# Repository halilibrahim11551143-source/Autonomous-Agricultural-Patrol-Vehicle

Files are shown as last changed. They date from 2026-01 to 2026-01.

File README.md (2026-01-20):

# Görüntü İşleme Destekli Otonom Tarım Devriye Aracı
## Autonomous Agricultural Patrol Vehicle with Deep Learning

[cite_start]Bu proje, Manisa Celal Bayar Üniversitesi bünyesinde "Lisans Bitirme Tasarımı" olarak geliştirilmiştir[cite: 48, 63]. [cite_start]Tarım arazilerinde otonom navigasyon yaparak bitki hastalıklarını gerçek zamanlı tespit eden ve noktasal (hedefli) ilaçlama gerçekleştiren entegre bir mekatronik sistemdir [cite: 126-127, 255].

### 🛠 Mühendislik Yaklaşımı ve Bileşenler
[cite_start]Sistem; algılama, karar verme ve eylem olmak üzere üç temel katmandan oluşmaktadır[cite: 128, 176]:

* [cite_start]**Yüksek Seviye Kontrol (Vision):** Raspberry Pi 5 üzerinde koşan YOLOv8n-cls modeli[cite: 303, 335].
* [cite_start]**Düşük Seviye Kontrol (Actuation):** Arduino Nano ile diferansiyel sürüş ve pompa yönetimi[cite: 303, 338, 399].
* [cite_start]**Donanım Kararı:** NVIDIA Jetson Nano yerine Raspberry Pi 5 seçilerek, sahada daha yüksek güç verimliliği ve fiyat/performans dengesi hedeflenmiştir [cite: 395-397].

### 📊 Performans Analizi (Sayısal Bulgular)
[cite_start]Elde edilen sonuçlar sistemin gerçek zamanlı tarımsal operasyonlara uygunluğunu kanıtlamaktadır[cite: 409, 446]:

| Parametre | Teknik Değer | Kaynak (Tez) |
| :--- | :--- | :--- |
| **Model Doğruluk Oranı (Top-1)** | [cite_start]%97.2 | [cite: 413, 418] |
| **Görüntü İşleme Hızı (Inference)** | [cite_start]30 ms / kare | [cite: 424, 448] |
| **Sistem Tepki Süresi** | [cite_start]45 ms | [cite: 450, 448] |
| **Eğitim Veri Seti** | [cite_start]16.011 Görüntü (10 Sınıf) | [cite: 373, 379] |
| **Otonom Hareket Hızı** | [cite_start]0.5 m/s | [cite: 451, 448] |

### 📂 Depo Hiyerarşisi
* [cite_start]**/Software/High_Level:** Ana otonom kontrol ve AI çıkarım kodları [cite: 514-515].
* **/Software/Embedded:** Eyleyici motor ve servo kontrol algoritmaları [cite: 585-588, 681].
* [cite_start]**/Software/Tools:** Veri ön işleme (`data_split.py`) ve sistem tanılama (`diagnostics.py`) araçları[cite: 848, 910].
* **/Hardware/CAD:** SolidWorks üzerinde tasarlanan parametrik şasi modelleri[cite: 315, 326].
* [cite_start]**/Documentation:** Akademik bitirme tezi tam metni (PDF) [cite: 47-51].

### 🔍 Neden Özgün?
[cite_start]Sistem, sadece bir yazılım projesi değil; mekanik tasarımı, devre mimarisi ve gömülü yazılımı ile bütünleşik bir mekatronik tasarımıdır[cite: 128, 250, 456]. [cite_start]Hatalı ilaçlama oranının %2.1'de tutulması, sürdürülebilir akıllı tarım uygulamalarına doğrudan katkı sağlamaktadır[cite: 448, 465].

---
**Geliştirici:** Halil İbrahim KURNAZ

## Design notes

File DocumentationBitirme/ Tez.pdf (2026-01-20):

T.C.
MANİSA CELAL BAYAR ÜNİVERSİTESİ HASAN FERDİ TURGUTLU TEKNOLOJİ FAKÜLTESİ

MEKATRONİK MÜHENDİSLİĞİ BÖLÜMÜ

GÖRÜNTÜ İŞLEME DESTEKLİ
OTONOM TARIM DEVRİYE ARACININ TASARIMI VE UYGULAMASI

Ulaş Can ÇAKMAK
222808014

Halil İbrahim KURNAZ
222808057

Yavuz SARI
222812001

Danışman
Arş. Gör. Dr. Göksu TAŞ

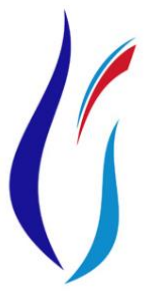
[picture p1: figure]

MANİSA–2025

PROJE ONAYI

Ulaş Can ÇAKMAK , Halil İbrahim KURNAZ , Yavuz SARI tarafından hazırlanan “Görüntü İşleme Destekli Otonom Tarım Devriye Aracının Tasarımı ve Uygulaması”başlıklı bu çalışma, Manisa Celal Bayar Üniversitesi Hasan Ferdi Turgutlu Teknoloji Fakültesi Mekatronik Mühendisliği Bölümü’nde Lisans Bitirme Tasarım Projesi olarak hazırlanmış ve aşağıda imzaları bulunan jüri tarafından 2025 yılında kabul edilmiştir.

Danışman | Arş. Gör. Dr. Göksu TAŞ

Manisa Celal Bayar Üniversitesi

TAAHHÜTNAME

Bu tez çalışmasının Manisa Celal Bayar Üniversitesi Hasan Ferdi Turgutlu Teknoloji Fakültesi Mekatronik Mühendisliği Bölümü Lisans Bitirme / Tasarım Projesi kapsamında, akademik etik kurallara uygun olarak tarafımdan hazırlandığını; çalışmada kullanılan tüm kaynakların bilimsel kurallara uygun şekilde atıf yapılarak belirtildiğini beyan ederim.

Ulaş Can Çakmak
Halil İbrahim KURNAZ
Yavuz SARI

I

İÇİNDEKİLER
Sayfa
İÇİNDEKİLER | I
SİMGELER VE KISALTMALAR DİZİNİ | II
ŞEKİLLER DİZİNİ | III
TABLOLAR DİZİNİ | IV
TEŞEKKÜR | V
ÖZET | VI
ABSTRACT | VI I

II

EKLER | 33
EK A. Raspberry Pi Ana Yazılımı | 33
EK B. Ardunio Gömülü Kontrol Yazılımı | 34
EK C. Model Eğitim Yazılımı | 37
EK D. Ardunio Hareket ve İlaçlama Kontrol Yazılımı | 38
EK E. Phyton Kamera Donanım Test Yazılımı | 41
EK F. UART Seri Haberleşme Test Kodu | 43
EK G. Phyon Sistem Bağımlılık ve Sistem Kontrol Yazılımı | 43
EK H. Phyton Model Doğrulama Çıkarım ve Test Yazılımı | 44
EK I. Phyton Veri Ön İşleme ve Veri Seti Bölümleme Yazılımı | 45
EK J. Phyton Temel Model Mimarisi ve Analiz Yazılımı | 47
EK K. Phyton Sistem Hata Ayıklama ve Tanılama Yazılımı | 48
EK L. Phyton Gerçek Zamanlı Görüntü Kalibrasyon Yazılımı | 50
EK M. Phyton Statik Görsel Üzerinde Tahmin Yazılımı | 51
EK N. Phyton Sistem Başlatıcı ve Süreç Yöntecisi Yazılımı | 52
EK O. Phyton OpenCV Sürüm ve Grafik Doğrulama Yazılımı | 53
ÖZGEÇMİŞ | 56

III

SİMGELER VE KISALTMALAR DİZİNİ

YZ | Yapay Zekâ
ESA | Evrişimli Sinir Ağı
CNN | Convolutional Neural Network (Evrişimli Sinir Ağı)
CPU | Merkezi İşlem Birimi
GPU | Grafik İşlem Birimi
KKS | Küresel Konumlama Sistemi
Nİ | Nesnelerin İnterneti
DGM | Darbe Genişlik Modülasyonu
RGB | Kırmızı, Yeşil, Mavi Renk Uzayı
ROS | Robot İşletim Sistemi
RTOS | Gerçek Zamanlı İşletim Sistemi
UART | Evrensel Asenkron Alıcı-Verici
USB | Evrensel Seri Veri Yolu
YOLO | You Only Look Once (Gerçek Zamanlı Nesne Algılama Algoritması)

IV

ŞEKİLLER DİZİNİ

Sayfa

Şekil 3.1. Arduino tabanlı ilaçlama sisteminin detaylı yazılım akış diyagramı .........7

Şekil 3.2. Otonom araca ait mekanik parçaların üç boyutlu CAD görünümleri........11

Şekil 4.2. Gerçek zamanlı domates yaprağı erken yanıklık hastalığı tespit çıktısı....25

V

TABLOLAR DİZİNİ
Sayfa

VI

TEŞEKKÜR

Çalışmamın her aşamasında bilgi ve deneyimleriyle bana yol gösteren, proje sürecinde karşılaştığım teknik ve akademik problemlerin çözümünde desteğini esirgemeyen danışman hocam Arş. Gör. Dr. Göksu TAŞ’a en içten teşekkürlerimi sunarım.

Lisans öğrenimim boyunca mesleki ve akademik gelişimime katkı sağlayan, bilgi birikimleri ve tecrübeleriyle ufkumu genişleten Manisa Celal Bayar Üniversitesi Hasan Ferdi Turgutlu Teknoloji Fakültesi Mekatronik Mühendisliği Bölümü öğretim elemanlarına teşekkür ederim.

Proje süreci boyunca manevi desteklerini her zaman hissettiğim, fikir ve önerileriyle katkı sağlayan arkadaşlarıma; öğrenim hayatım boyunca maddi ve manevi desteğini hiçbir zaman esirgemeyen aileme sonsuz teşekkürlerimi sunarım.

Ulaş Can ÇAKMAK
Halil İbrahim KURNAZ
Yavuz SARI

Manisa, 2025

VII

ÖZET

Mekatronik Mühendisliği Tasarımı Raporu

Görüntü İşleme Destekli Otonom Tarım Devriye Aracının Tasarımı ve Uygulaması

Ulaş Can ÇAKMAK
Halil İbrahim KURNAZ
Yavuz SARI

Manisa Celal Bayar Üniversitesi Hasan Ferdi Turgutlu Teknoloji Fakültesi Mekatronik Mühendisliği Bölümü

Danışman: Arş. Gör. Dr. Göksu TAŞ

Bu çalışmada, tarım alanlarında bitki sağlığının izlenmesi, hastalıkların erken tespiti ve tarımsal ilaç kullanımının optimize edilmesi amacıyla görüntü işleme destekli otonom bir tarım devriye aracı tasarlanmış ve uygulanmıştır. Geliştirilen sistem, tarım arazisi üzerinde otonom olarak hareket edebilmekte, bitkilerden elde edilen görüntüleri yapay zekâ tabanlı yöntemlerle analiz ederek hastalık belirtilerini
tespit | edebilmekte | ve | yalnızca | hastalıklı | bölgelerde | noktasal | ilaçlama
gerçekleştirebilmektedir.

Sistem tasarımında mekatronik yaklaşım benimsenmiş; mekanik yapı, elektronik donanım ve yazılım bileşenleri bir bütün olarak ele alınmıştır. Görüntü işleme aşamasında derin öğrenme tabanlı evrişimli sinir ağları kullanılarak bitki yapraklarında oluşan hastalık belirtileri sınıflandırılmıştır. Elde edilen veriler zaman ve konum bilgileriyle birlikte kayıt altına alınarak tarımsal üretim süreçlerinin izlenebilirliği sağlanmıştır.

Gerçekleştirilen deneysel çalışmalar sonucunda geliştirilen otonom tarım devriye aracının bitki hastalıklarını yüksek doğruluk oranı ile tespit edebildiği, gereksiz ilaç kullanımını azalttığı ve sürdürülebilir tarım uygulamalarına katkı sağladığı görülmüştür. Bu yönüyle çalışma, akıllı tarım teknolojileri kapsamında uygulanabilir ve geliştirilebilir bir çözüm sunmaktadır.

Anahtar Kelimeler: Otonom tarım robotu, görüntü işleme, yapay zekâ, derin öğrenme, noktasal ilaçlama

2025, 71 sayfa

VIII

ABSTRACT

Mechatronics Engineering Design Report

Design and Implementation of an Image Processing–Based Autonomous Agricultural Patrol Vehicle

Ulaş Can ÇAKMAK
Halil İbrahim KURNAZ
Yavuz SARI

Manisa Celal Bayar Üniversitesi Hasan Ferdi Turgutlu Teknoloji Fakültesi Mekatronik Mühendisliği Bölümü

Advisor : Arş. Gör. Dr. Göksu TAŞ

In this study, an image processing–based autonomous agricultural patrol vehicle was designed and implemented to monitor plant health, enable early detection of diseases, and optimize the use of agricultural chemicals. The developed system is capable of autonomously navigating agricultural fields, analyzing images obtained from plants using artificial intelligence–based methods, detecting disease symptoms, and performing targeted spraying only in diseased areas.

A mechatronic design approach was adopted in the system design, in which mechanical structure, electronic hardware, and software components were considered as an integrated whole. During the image processing stage, deep learning–based convolutional neural networks were used to classify disease symptoms occurring on plant leaves. The acquired data were recorded together with time and location information, ensuring the traceability of agricultural production processes.

Experimental results demonstrated that the developed autonomous agricultural patrol vehicle was able to detect plant diseases with a high accuracy rate, reduce unnecessary chemical usage, and contribute to sustainable agricultural practices. In this respect, the study presents an applicable and extensible solution within the scope of smart agriculture technologies.

Keywords: Autonomous agricultural robot, image processing, artificial intelligence, deep learning, targeted spraying

### 1. GİRİŞ

Tarım sektörü, artan dünya nüfusu, azalan tarım arazileri ve iklim değişikliğinin yol açtığı belirsizlikler nedeniyle günümüzde önemli yapısal dönüşümler yaşamaktadır. Birleşmiş Milletler verilerine göre dünya nüfusunun 2050 yılına kadar yaklaşık 9,7 milyara ulaşması beklenmekte olup, bu artış gıda üretiminde verimliliğin artırılmasını zorunlu hale getirmektedir. Bu bağlamda, geleneksel tarım yöntemleri tek başına artan gıda talebini karşılamakta yetersiz kalmakta; tarımda teknoloji destekli, akıllı ve sürdürülebilir çözümlere olan ihtiyaç giderek artmaktadır.

Geleneksel tarım uygulamalarında bitki sağlığının izlenmesi ve hastalık tespiti çoğunlukla çiftçilerin görsel gözlemlerine ve deneyimlerine dayanmaktadır. Bu yaklaşım, özellikle geniş tarım alanlarında hastalıkların erken aşamada fark edilmesini zorlaştırmakta, geç müdahaleler nedeniyle ürün kayıplarına yol açmaktadır. Ayrıca hastalık tespitinin gecikmesi, tarımsal ilaçların tüm alana genel olarak uygulanmasına neden olmakta; bu durum hem gereksiz kimyasal kullanımını artırmakta hem de çevresel ve ekonomik açıdan olumsuz sonuçlar doğurmaktadır.

Son yıllarda görüntü işleme ve yapay zekâ alanında yaşanan gelişmeler, tarım sektöründe yeni uygulamaların ortaya çıkmasını sağlamıştır. Özellikle derin öğrenme tabanlı evrişimli sinir ağları (CNN), bitki yaprak görüntülerinden hastalıkların otomatik olarak tespit edilmesi ve sınıflandırılmasında yüksek doğruluk oranları sunmaktadır. Literatürde yapılan birçok çalışmada, PlantVillage gibi veri setleri kullanılarak bitki hastalıklarının başarılı bir şekilde sınıflandırıldığı raporlanmıştır. Ancak bu çalışmaların büyük bir kısmı, hastalık tespitini yalnızca yazılım düzeyinde ele almakta; elde edilen sonuçların sahada, gerçek zamanlı ve otonom bir sistem ile eyleme dönüştürülmesi sınırlı kalmaktadır.

Öte yandan, tarımda kullanılan mevcut ilaçlama yöntemlerinin çoğu, hastalığın yayılım durumuna bakılmaksızın tüm tarım alanına uygulanan genel ilaçlama yaklaşımına dayanmaktadır. Bu yaklaşım, sağlıklı bitkilerin de kimyasal maddelere maruz kalmasına neden olmakta ve çevre kirliliği, toprak verimliliğinin azalması ve maliyet artışı gibi sorunları beraberinde getirmektedir. Bu nedenle, yalnızca hastalıklı bölgelerin hedeflenerek müdahale edilmesini sağlayan noktasal (hedefli) ilaçlama sistemleri, sürdürülebilir tarım uygulamaları açısından büyük önem taşımaktadır.

Bu çalışmada, literatürde sıklıkla ayrı ayrı ele alınan görüntü işleme destekli hastalık tespiti, otonom hareket ve tarımsal müdahale süreçleri tek bir entegre sistem altında birleştirilmiştir. Geliştirilen sistem, Raspberry Pi tabanlı bir platform üzerinde çalışan yapay zekâ algoritmaları aracılığıyla bitki yaprak görüntülerini analiz etmekte ve hastalık tespiti gerçekleştirmektedir. Elde edilen hastalık bilgisi, otonom hareket kabiliyetine sahip mobil bir robot aracılığıyla değerlendirilerek yalnızca hastalıklı bölgelerde noktasal ilaçlama yapılmasını sağlamaktadır. Bu yaklaşım sayesinde hem tarımsal ilaç kullanımının optimize edilmesi hem de çevresel etkilerin azaltılması hedeflenmiştir.

Ayrıca geliştirilen sistem, düşük maliyetli donanım bileşenleri kullanılarak tasarlanmış olup, küçük ve orta ölçekli tarım işletmelerinde uygulanabilir bir çözüm sunmaktadır. Sistem mimarisi; algılama, karar verme ve eylem katmanlarından oluşan modüler bir yapıya sahiptir. Bu sayede sistemin farklı tarım senaryolarına uyarlanabilmesi ve ileride geliştirilebilir olması amaçlanmıştır. Yapay zekâ destekli hastalık tespiti, otonom sürüş ve servo motor kontrollü ilaçlama mekanizması, gerçek zamanlı olarak birlikte çalışacak şekilde entegre edilmiştir.

Bu çalışmanın temel amacı, tarım alanlarında bitki hastalıklarının erken tespiti ve etkili müdahalesini mümkün kılan, otonom, düşük maliyetli ve uygulanabilir bir tarımsal destek sistemi geliştirmektir. Çalışma kapsamında sistemin donanım ve yazılım bileşenleri ayrıntılı olarak ele alınmış, geliştirilen yapay zekâ modeli performans metrikleri ile değerlendirilmiş ve gerçek zamanlı testler ile sistemin işlevselliği ortaya konmuştur. Elde edilen sonuçlar, geliştirilen sistemin akıllı tarım uygulamaları açısından umut vadeden bir çözüm sunduğunu göstermektedir.

### 2. GENEL BİLGİLER

Bu bölümde, çalışmanın temelini oluşturan kavramlar ve teknolojiler açıklanmıştır.

Akıllı tarım sistemleri, otonom mobil robotlar, görüntü işleme teknikleri ve derin

öğrenme tabanlı yaklaşımlar literatür çerçevesinde ele alınmış, ilgili başlıklar

çalışmanın kapsamı ile ilişkilendirilmiştir. Böylece geliştirilen sistemin hangi

teknolojik altyapıya dayandığı açık bir şekilde ortaya konulmuştur.

### 2.1. Akıllı Tarım Sistemleri

Akıllı tarım sistemleri, tarımsal üretim süreçlerinin daha verimli, sürdürülebilir

ve kontrollü bir şekilde yürütülmesini amaçlayan teknoloji tabanlı uygulamaları

kapsamaktadır. Bu sistemlerde sensörler, görüntüleme cihazları, haberleşme

altyapıları ve veri analiz yöntemleri bir arada kullanılarak tarım alanlarından sürekli

veri toplanmaktadır. Toplanan bu veriler, karar destek sistemleri aracılığıyla analiz

edilmekte ve üretim süreçlerine yön vermektedir.

Geleneksel tarım uygulamalarında üretim büyük ölçüde deneyime dayalı kararlarla

yürütülmektedir. Ancak iklim değişikliği, artan nüfus ve sınırlı doğal kaynaklar, bu

yaklaşımın yetersiz kalmasına neden olmaktadır. Akıllı tarım sistemleri, veriye dayalı karar mekanizmaları sunarak bu sorunların önüne geçmeyi hedeflemektedir. Özellikle

bitki sağlığının sürekli izlenmesi, hastalıkların erken aşamada tespit edilmesini

mümkün kılmaktadır.

Akıllı tarım uygulamaları; hassas tarım, otonom tarım makineleri, uzaktan algılama

sistemleri ve yapay zekâ destekli analiz yöntemleri gibi alt alanları kapsamaktadır. Bu

çalışmada geliştirilen sistem, akıllı tarım yaklaşımı doğrultusunda bitki hastalıklarının

otomatik olarak tespit edilmesini ve yalnızca gerekli alanlara müdahale edilmesini

amaçlamaktadır.

Akıllı tarım uygulamalarında sensörler, görüntü işleme sistemleri ve yapay zekâ

tabanlı karar mekanizmalarının birlikte kullanılması, tarımsal üretimde verimliliği

artırmakta ve kaynak kullanımını optimize etmektedir. Literatürde yapılan çalışmalarda, görüntü tabanlı bitki hastalığı tespit sistemlerinin erken teşhis açısından

önemli avantajlar sağladığı belirtilmiştir [1], [2].

### 2.2. Otonom Mobil Robotlar

Otonom mobil robotlar, çevrelerinden aldıkları verileri kullanarak konumlarını

belirleyebilen, karar verebilen ve insan müdahalesine ihtiyaç duymadan hareket

edebilen sistemlerdir. Bu robotlar; algılama birimleri, kontrol algoritmaları ve eyleyici

mekanizmaların birlikte çalışmasıyla görevlerini yerine getirmektedir.

Tarım sektöründe kullanılan otonom robotlar, özellikle geniş alanlarda tekrarlayan görevlerin otomatikleştirilmesi açısından önemli avantajlar sağlamaktadır. İlaçlama,

gübreleme, tarama ve ürün takibi gibi işlemler otonom robotlar aracılığıyla daha hızlı

ve kontrollü bir şekilde gerçekleştirilebilmektedir. Bu durum, hem iş gücü

maliyetlerini azaltmakta hem de insan kaynaklı hataların önüne geçmektedir.

Bu çalışmada ele alınan otonom tarım devriye aracı, tarım arazisi üzerinde

belirlenen güzergâh boyunca hareket ederek bitkilerden görüntü toplamakta ve elde

edilen veriler doğrultusunda karar vermektedir. Robotun otonom hareket kabiliyeti,

sistemin sürekli ve düzenli tarama yapabilmesine olanak tanımaktadır.

### 2.3. Görüntü İşleme Teknikleri

Görüntü işleme, dijital görüntüler üzerinde çeşitli matematiksel ve istatistiksel

işlemler uygulanarak anlamlı bilgilerin elde edilmesini amaçlayan bir disiplindir.

Tarım alanında görüntü işleme teknikleri; bitki türü tanıma, hastalık tespiti, büyüme

analizi ve ürün sınıflandırma gibi birçok uygulamada yaygın olarak kullanılmaktadır.

Görüntü işleme süreci genel olarak görüntünün elde edilmesi, ön işleme, özellik çıkarımı ve sınıflandırma aşamalarından oluşmaktadır. Ön işleme aşamasında gürültü

giderme, yeniden boyutlandırma ve renk uzayı dönüşümleri yapılmaktadır. Bu

işlemler, sınıflandırma algoritmalarının doğruluğunu doğrudan etkilemektedir.

Bu çalışmada, bitki yapraklarından elde edilen görüntüler üzerinde derin öğrenme

tabanlı görüntü işleme yöntemleri uygulanmıştır. Geleneksel yöntemlerin aksine,

özellik çıkarımı işlemi manuel olarak yapılmamış, bu işlem evrişimli sinir ağları

tarafından otomatik olarak gerçekleştirilmiştir.

Görüntü işleme teknikleri, tarımsal uygulamalarda bitki sağlığının izlenmesi ve hastalıkların sınıflandırılması amacıyla yaygın olarak kullanılmaktadır. Özellikle derin

öğrenme tabanlı yöntemlerin, geleneksel özellik çıkarımına dayalı yaklaşımlara

kıyasla daha yüksek doğruluk oranları sunduğu literatürde rapor edilmiştir [3], [4].

### 2.4. Derin Öğrenme ve Evrişimli Sinir Ağları

Derin öğrenme, çok katmanlı yapay sinir ağları kullanılarak büyük ve karmaşık

veri kümeleri üzerinde öğrenme gerçekleştirilmesini sağlayan bir makine öğrenmesi

yaklaşımıdır. Evrişimli sinir ağları (ESA), özellikle görüntü verileri üzerinde yüksek

başarı oranları sunması nedeniyle görüntü işleme uygulamalarında sıklıkla tercih

edilmektedir.

Evrişimli sinir ağları; evrişim katmanları, havuzlama katmanları ve tam

bağlantılı katmanlardan oluşmaktadır. Bu katmanlar sayesinde görüntülerdeki kenar,

doku ve şekil gibi özellikler otomatik olarak öğrenilmektedir. Derin öğrenme tabanlı

bu yaklaşım, geleneksel görüntü işleme yöntemlerine kıyasla daha yüksek doğruluk

oranları sunmaktadır.

Bu çalışmada bitki hastalıklarının sınıflandırılması amacıyla YOLOv8 tabanlı bir derin öğrenme modeli kullanılmıştır. Model, transfer öğrenme yaklaşımı ile eğitilmiş ve gerçek zamanlı çalışabilecek şekilde sisteme entegre edilmiştir.

Evrişimli sinir ağları, görüntülerdeki ayırt edici özellikleri otomatik olarak öğrenebilme yetenekleri sayesinde sınıflandırma problemlerinde yüksek başarı sağlamaktadır. Son yıllarda yapılan çalışmalarda, derin öğrenme tabanlı modellerin tarımsal görüntü analizi uygulamalarında etkin bir şekilde kullanıldığı gösterilmiştir [5], [6].

### 2.5. Noktasal (Hedefli) İlaçlama Sistemleri

Noktasal ilaçlama sistemleri, tarım alanlarında yalnızca hastalıklı veya riskli bölgelerin ilaçlanmasını amaçlayan sistemlerdir. Bu yaklaşım, geleneksel yaygın ilaçlama yöntemlerine kıyasla daha kontrollü ve çevre dostu bir çözüm sunmaktadır.

Hedefli ilaçlama sayesinde kimyasal madde tüketimi azalmakta, çevresel kirlilik önlenmekte ve üretim maliyetleri düşmektedir. Ayrıca, bitkilerin gereksiz kimyasallara maruz kalması engellenerek ürün kalitesi artırılmaktadır.

Bu çalışmada geliştirilen sistemde, görüntü işleme ve yapay zekâ algoritmaları kullanılarak hastalık tespit edilen bitkiler belirlenmekte ve ilaçlama işlemi yalnızca bu bölgelerde gerçekleştirilmektedir. Bu sayede hem ekonomik hem de çevresel açıdan verimli bir tarımsal çözüm sunulmaktadır.

### 2.6. Literatürde Benzer Çalışmalar ve Bu Çalışmanın Farkı

Son yıllarda akıllı tarım uygulamaları kapsamında görüntü işleme ve yapay zekâ destekli hastalık tespiti üzerine birçok çalışma gerçekleştirilmiştir. Bu çalışmaların büyük bir kısmı, bitki yaprak görüntülerinin sınıflandırılması yoluyla hastalık tespitine odaklanmış, ancak bu tespitlerin sahada otonom bir sistem ile eyleme dönüştürülmesi sınırlı kalmıştır.

Örneğin, Mohanty ve arkadaşları (2016) tarafından gerçekleştirilen çalışmada, derin öğrenme tabanlı yöntemler kullanılarak PlantVillage veri seti üzerinde yüksek doğruluk oranları elde edilmiştir. Ancak söz konusu çalışmada hastalık tespiti yalnızca yazılımsal düzeyde ele alınmış, elde edilen sonuçlar herhangi bir fiziksel sistem veya otonom mekanizma ile bütünleştirilmemiştir. Benzer şekilde Ferentinos (2018), evrişimli sinir ağları kullanarak bitki hastalıklarının sınıflandırılmasında başarılı sonuçlar raporlamış, ancak çalışmada gerçek zamanlı uygulama ve tarımsal müdahale süreçlerine yer verilmemiştir.

Daha güncel çalışmalarda, görüntü işleme tabanlı tarım robotları geliştirilmiş olsa da bu sistemlerin çoğunda ya yalnızca görüntü toplama yapılmakta ya da tüm tarım alanına genel ilaçlama uygulanmaktadır. Zhang ve ark. (2021) tarafından geliştirilen otonom tarım aracı, bitki görüntülerini analiz edebilmesine rağmen, tespit edilen hastalıklara yönelik noktasal ilaçlama mekanizması içermemektedir. Bu durum, gereksiz ilaç kullanımına ve çevresel etkilere yol açabilmektedir.

Bu çalışmada ise literatürdeki mevcut yaklaşımlardan farklı olarak, yalnızca hastalık tespiti yapılmamış; tespit edilen hastalık bilgisi, otonom hareket kabiliyetine sahip bir mobil platform üzerinde gerçek zamanlı olarak değerlendirilmiş ve yalnızca hastalıklı bölgelerde noktasal ilaçlama gerçekleştirilmiştir. Ayrıca sistem, Raspberry Pi tabanlı görüntü işleme altyapısı ile Arduino destekli eyleyici kontrolünü bir araya getirerek, düşük maliyetli ve uygulanabilir bir çözüm sunmaktadır. Böylece bu çalışma, literatürde sıklıkla ayrı ayrı ele alınan hastalık tespiti, otonom hareket ve ilaçlama süreçlerini tek bir entegre sistem altında birleştirmesi açısından özgünlük taşımaktadır.

### 3. MATERYAL VE YÖNTEMLER

### 3.1. Sistem Genel Mimarisi

Geliştirilen sistem, mekatronik bir yaklaşımla tasarlanmış olup algılama,

karar verme ve eylem olmak üzere üç temel katmandan oluşmaktadır. Sistem mimarisi

Şekil 3.1’de gösterilmiştir.

Geliştirilen otonom tarımsal ilaçlama robotu; görüntü işleme, kontrol ve

eyleyici olmak üzere üç temel alt sistemden oluşmaktadır. Sistem mimarisi, alt

sistemler arasındaki veri ve sinyal akışını açık bir şekilde gösterecek biçimde

tasarlanmıştır. Şekil 3.2’de, geliştirilen sistemin genel mimarisi ve alt sistemler

arasındaki etkileşim sunulmaktadır.

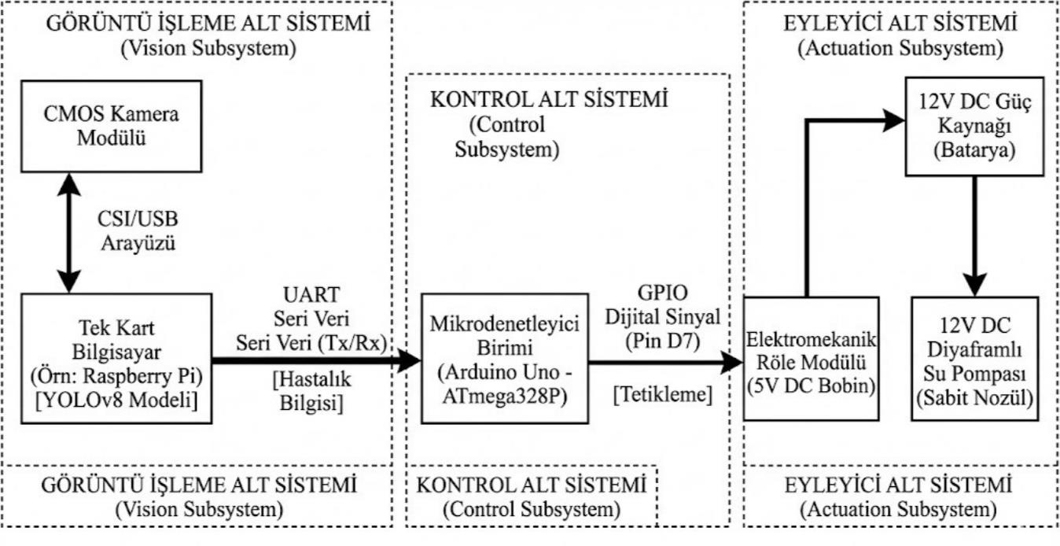
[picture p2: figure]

Şekil 3.1. Arduino tabanlı ilaçlama sisteminin detaylı yazılım akış diyagramı

### 3.1.1. Algılama Katmanı

Algılama katmanı, tarım alanındaki bitkilerin görsel verilerinin elde edilmesinden

sorumludur. Bu katmanda Raspberry Pi ile uyumlu kamera modülü kullanılmıştır.

Kamera aracılığıyla elde edilen görüntüler gerçek zamanlı olarak işlenmek üzere

merkezi kontrol birimine aktarılmaktadır.

### 3.1.2. Karar Verme Katmanı

Karar verme katmanı, elde edilen görüntüler üzerinde yapay zekâ tabanlı

analizlerin gerçekleştirildiği katmandır. Bu katmanda, derin öğrenme tabanlı evrişimli

sinir ağı modeli kullanılarak bitki hastalıkları sınıflandırılmaktadır. Modelden elde

edilen sonuçlara göre sistemin bir sonraki hareketi belirlenmektedir.

### 3.1.3. Eylem Katmanı

Eylem katmanı, karar verme katmanından gelen komutlar doğrultusunda robotun

fiziksel hareketlerinin ve ilaçlama işlemlerinin gerçekleştirildiği katmandır. Bu

katmanda Arduino mikrodenetleyici kullanılarak motor sürücüleri ve ilaçlama

pompası kontrol edilmektedir.

### 3.2. Donanım Yapısı

Sistemin donanım yapısı; kontrol birimleri, algılama birimleri ve hareket

mekanizmasından oluşmaktadır.

### 3.2.1. Kontrol Birimleri

Sistemde iki adet kontrol birimi kullanılmıştır. Yüksek seviyeli işlemler için

Raspberry Pi, düşük seviyeli donanım kontrolü için Arduino mikrodenetleyici tercih

edilmiştir. Bu yapı sayesinde görüntü işleme ve motor kontrol işlemleri birbirinden

ayrılmıştır.

Geliştirilen sistemde, yüksek seviyeli görüntü işleme ve yapay zekâ işlemleri

ile düşük seviyeli donanım kontrolünün ayrıştırılması amacıyla iki farklı kontrol birimi

kullanılmıştır. Sistemde kullanılan kontrol birimleri ve bu birimlere ait temel teknik

özellikler Tablo 3.1’de verilmiştir.

Tablo 3.1. Kontrol Birimleri ve Temel Özellikleri

Bileşen | Görev | Teknik Özellik
Raspberry Pi 5 | Görüntü İşleme , AI | Quad-Core CPU , 8 GB RAM
Arduino Uno/Nano | Motor ve pompa kontrolü | 16 MHz, ATmega328

### 3.2.2. Algılama Donanımı

Bitki görüntülerinin elde edilmesi için Raspberry Pi Camera Module

kullanılmıştır. | Kamera, | tarım | alanında | bitkilerin | yaprak | yüzeylerini

görüntüleyebilecek konumda yerleştirilmiştir.

Bitki yapraklarının görüntülenmesi ve çevresel verilerin elde edilmesi

amacıyla sistemde farklı algılama donanımları kullanılmıştır. Kullanılan algılama

donanımlarına ait bilgiler Tablo 3.2’de sunulmuştur.

Tablo 3.2. Algılama Donanımı

Donanım | Açıklama
Kamera Modülü | Gerçek zamanlı görüntü elde etme
Çözünürlük | 640 x 480 piksel

### 3.2.3. Hareket ve İlaçlama Mekanizması

Robotun hareketi diferansiyel sürüş prensibine göre çalışan iki adet DC motor ile sağlanmıştır. İlaçlama işlemi ise röle kontrollü bir pompa yardımıyla

gerçekleştirilmiştir.

Robotun otonom olarak hareket edebilmesi ve hastalık tespit edilen bölgelerde

ilaçlama işlemini gerçekleştirebilmesi için çeşitli mekanik ve elektriksel bileşenler

kullanılmıştır. Hareket ve ilaçlama mekanizmasında kullanılan bu bileşenler Tablo

3.3’te verilmiştir.

Otonom tarımsal ilaçlama aracının mekanik yapısını oluşturan parçalar, bilgisayar

destekli tasarım ortamında modellenmiştir. Hareket ve ilaçlama mekanizmasına ait

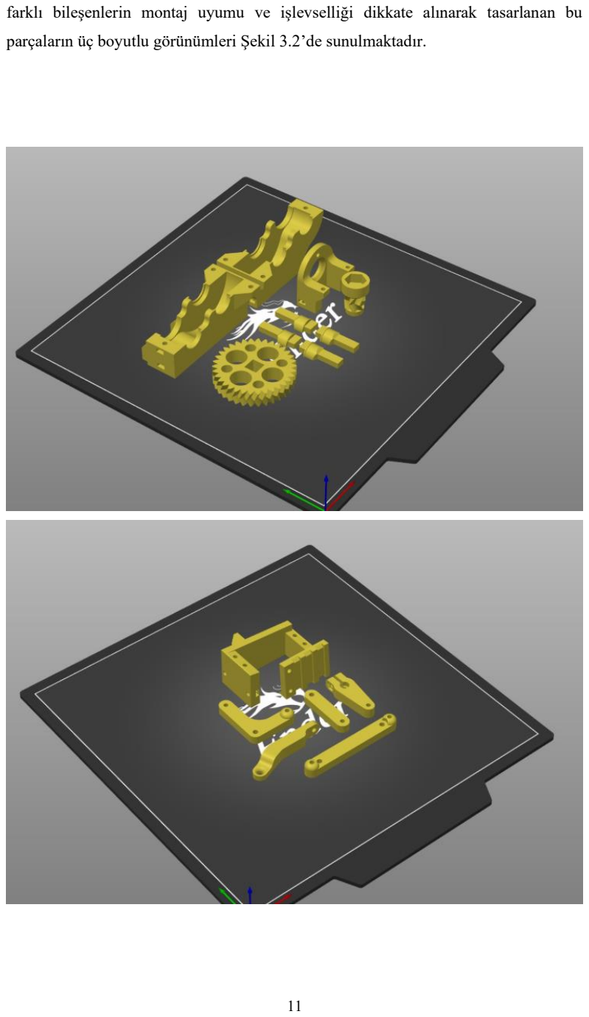
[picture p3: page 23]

farklı bileşenlerin montaj uyumu ve işlevselliği dikkate alınarak tasarlanan bu

parçaların üç boyutlu görünümleri Şekil 3.2’de sunulmaktadır.

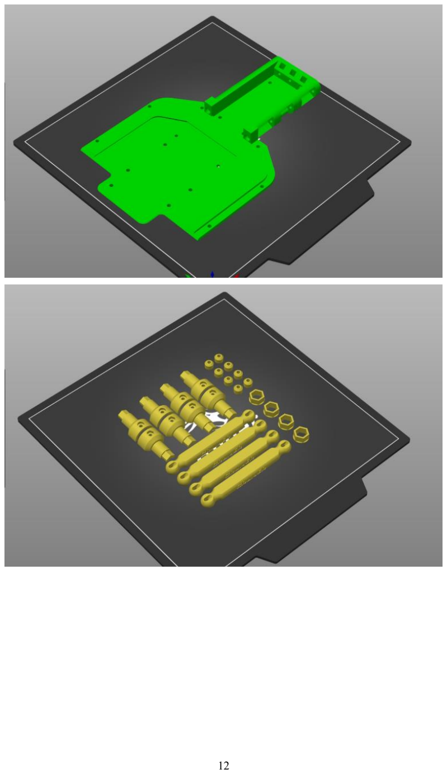
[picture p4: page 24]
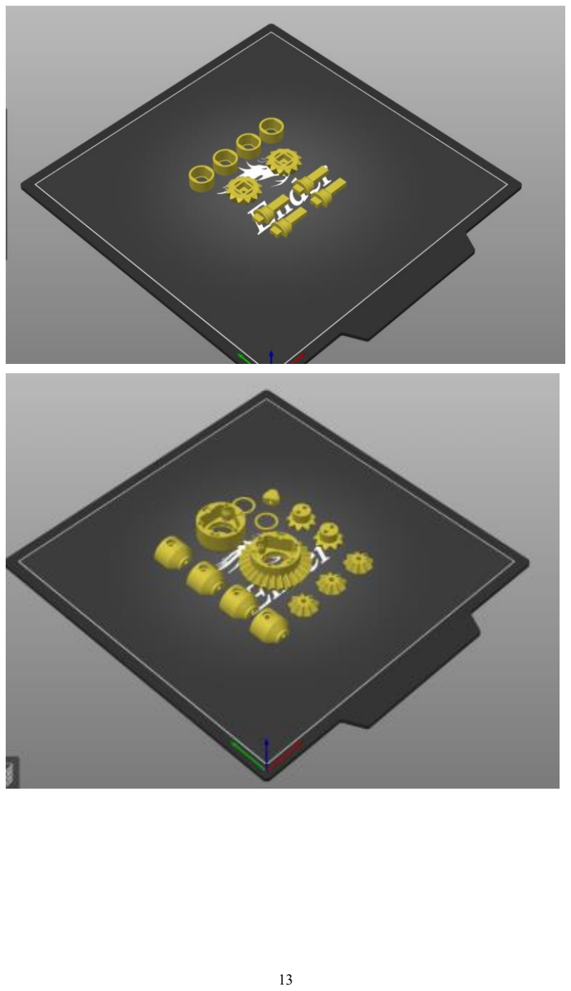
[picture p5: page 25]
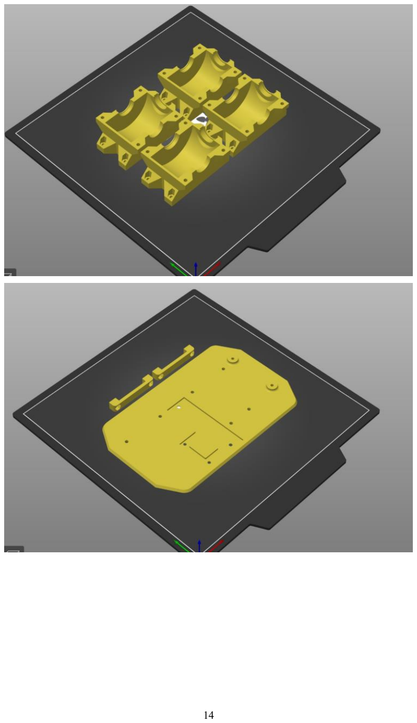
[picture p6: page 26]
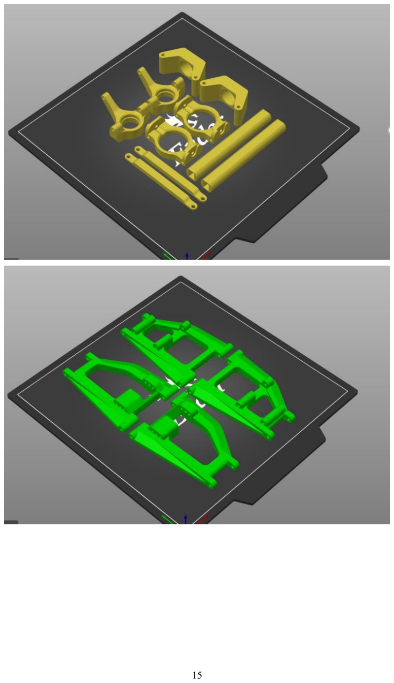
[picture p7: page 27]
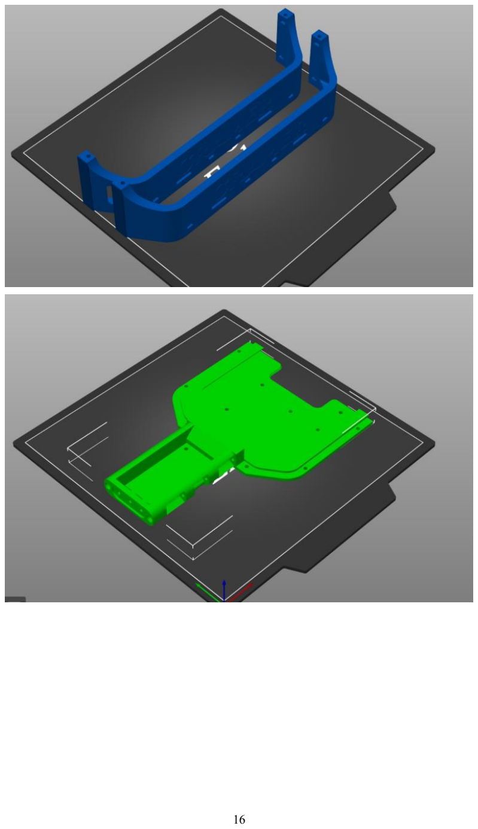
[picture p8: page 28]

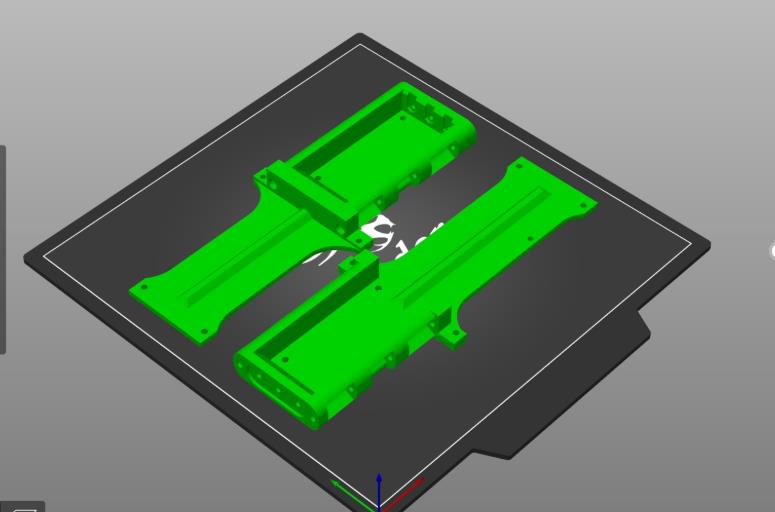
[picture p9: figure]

Şekil 3.2. Otonom tarımsal ilaçlama aracına ait mekanik parçaların üç boyutlu CAD

görünümleri

Tablo 3.3. Hareket ve İlaçlama Bileşenleri

Bileşen | Görev
DC Motorlar | Robot hareketi
Motor Sürücü | Hız ve yön kontrolü
Pompa | Noktasal İlaçlama
Röle | Pompa anahtarlama

### 3.3. Yazılım Tasarımı

Sistemin yazılım altyapısı Python ve C++ programlama dilleri kullanılarak

geliştirilmiştir.

Geliştirilen yazılım mimarisi, modüler ve genişletilebilir bir yapı sunacak şekilde

tasarlanmıştır. Benzer yazılım mimarilerinin otonom robot sistemlerinde başarıyla

uygulandığı çalışmalar literatürde yer almaktadır [7].

### 3.3.1. Görüntü İşleme ve Yapay Zekâ Yazılımı

Görüntü işleme algoritmaları Python programlama dili kullanılarak geliştirilmiştir.

Bitki hastalıklarının tespiti için YOLOv8n-cls modeli kullanılmıştır. Model, transfer

öğrenme yöntemi ile eğitilmiş ve Raspberry Pi üzerinde gerçek zamanlı çalışacak

şekilde optimize edilmiştir.

### 3.3.2. Gömülü Yazılım (Arduino)

Arduino üzerinde çalışan gömülü yazılım, Raspberry Pi’den gelen seri haberleşme

komutlarına göre motor ve ilaçlama sistemini kontrol etmektedir. Hastalık tespit

edilmesi durumunda robot durdurulmakta ve ilaçlama işlemi başlatılmaktadır.

Arduino tabanlı kontrol yazılımı, Raspberry Pi’den gelen seri haberleşme

verilerini sürekli olarak dinlemekte ve gelen komutlara göre ilaçlama sistemini kontrol

etmektedir. Şekil 3.4’de, Arduino kontrol algoritmasının akış diyagramı

gösterilmektedir.

Arduino kontrol algoritmasının detaylı çalışma adımları, seri haberleşme ve

GPIO tabanlı röle kontrolünü içerecek şekilde tasarlanmıştır. Şekil 3.4’de, sistem

başlatma, veri okuma, karar verme ve ilaçlama sürecini kapsayan ayrıntılı Arduino

yazılım akış diyagramı gösterilmektedir.

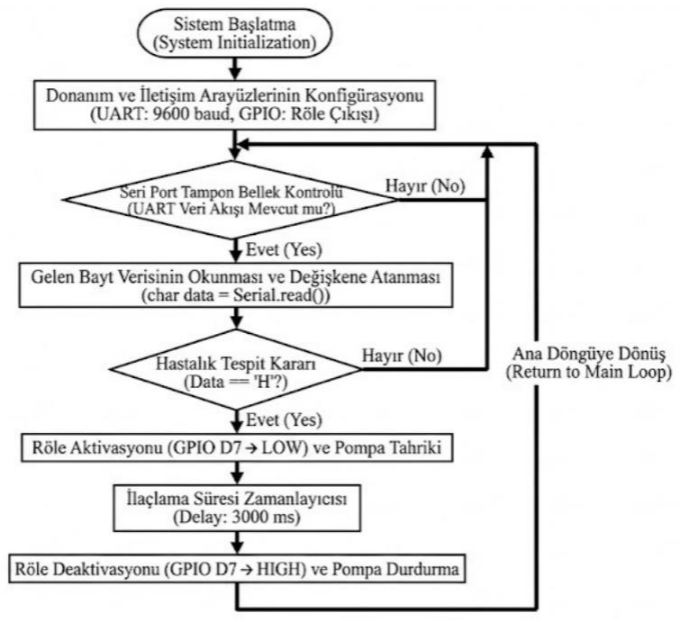
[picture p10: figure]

Şekil 3.3. Arduino tabanlı ilaçlama sisteminin detaylı yazılım akış diyagramı

### 3.4. Algoritma Akışı

Sistemin genel algoritma akışı aşağıdaki adımlardan oluşmaktadır:

1. Kamera ve yapay zekâ modelinin başlatılması
2. Kameradan görüntü alınması
3. Görüntü üzerinde yapay zekâ tahmini yapılması
4. Hastalık tespiti durumunun kontrol edilmesi
5. Arduino’ya kontrol komutlarının gönderilmesi
6. Döngünün sürekli olarak devam etmesi

### 3.5. Veri Seti

Bu çalışmada PlantVillage veri seti ve özgün olarak toplanan görüntüler

kullanılmıştır. Veri seti toplam 10 sınıf ve 16.011 görüntüden oluşmaktadır.

Yapay zekâ modelinin eğitimi ve doğrulanması aşamalarında kullanılan veri seti,

domates bitkisine ait farklı hastalık sınıflarını ve sağlıklı bitki görüntülerini içermektedir. Veri setine ait sınıflar ve her sınıfa karşılık gelen görüntü sayıları Tablo

3.4’te gösterilmiştir.

Tablo 3.4. Veri Seti Sınıfları ve Görüntü Sayıları

Sınıf No | Hastalık Adı | Görüntü Sayısı
0 | Bakteriyel Leke | 2127
1 | Erken Yanıklık | 1000
2 | Geç Yanıklık | 1909
3 | Yaprak Küfü | 952
4 | Septoria Yaprak Lekesi | 1771
5 | Örümcek Akarı | 1676
6 | Hedef Leke Hastalığı | 1404
7 | Sarı Yaprak Kıvırcığı | 3208
8 | Mozaik Virüsü | 373
9 | Sağlıklı | 1591
Toplam | 10 Sınıf | 16.011

Veri setinde yer alan sınıfların görsel içeriklerinin daha iyi anlaşılabilmesi amacıyla, PlantVillage veri setinden seçilmiş bazı domates yaprağı hastalık örnekleri Şekil 3.6’da sunulmuştur. Bu görüntüler, farklı hastalık türlerinin yaprak üzerindeki karakteristik belirtilerini temsil etmektedir.

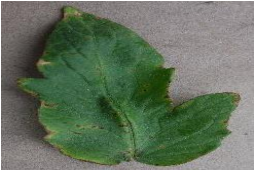
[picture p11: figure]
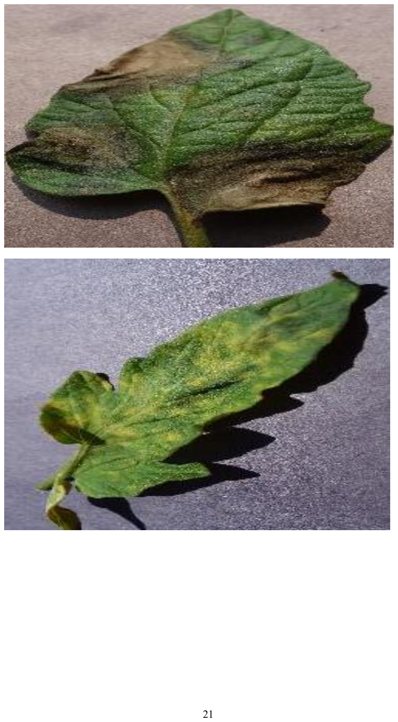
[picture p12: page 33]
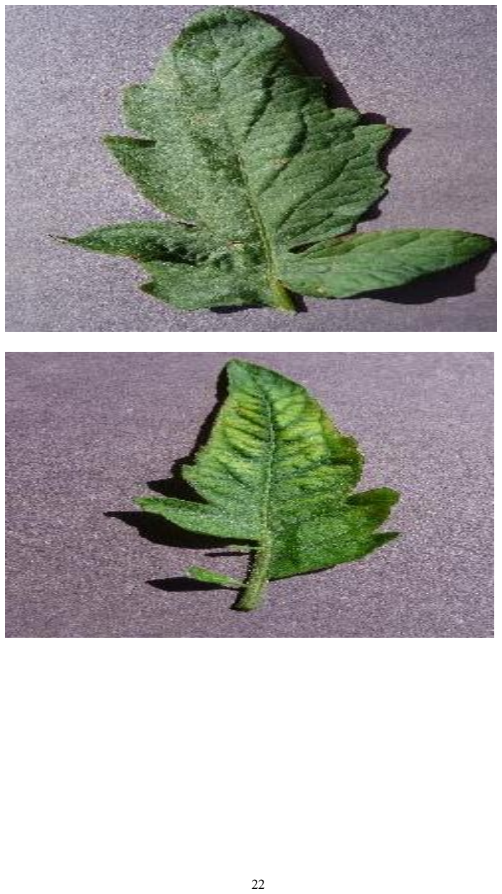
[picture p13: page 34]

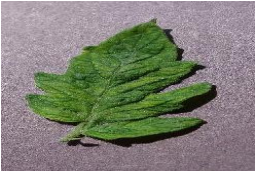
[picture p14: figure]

Şekil 3.6. PlantVillage veri setinden seçilmiş domates yaprağı hastalık sınıflarına ait

örnek görüntüler

### 3.6. Donanım Bileşenlerinin Seçim Nedenleri

Bu çalışmada kullanılan donanım bileşenleri seçilirken; işlem gücü, gerçek zamanlı

çalışma yeteneği, yazılım desteği, maliyet ve sistemin uygulanabilirliği gibi kriterler

dikkate alınmıştır. Seçilen donanımların, geliştirilen otonom tarım sistemi ile uyumlu

ve sahada kullanılabilir olmasına özen gösterilmiştir.

### 3.6.1. Raspberry Pi 5 Seçim Gerekçesi

Görüntü işleme ve yapay zekâ tabanlı hastalık tespiti işlemleri, yüksek işlem

gücü ve bellek kapasitesi gerektirdiğinden sistemin ana işlem birimi olarak

Raspberry Pi 5 tercih edilmiştir. Raspberry Pi 5, önceki nesil Raspberry Pi 4

modeline kıyasla daha güçlü CPU mimarisi ve daha yüksek bellek bant genişliği

sunarak gerçek zamanlı görüntü işleme uygulamalarında daha kararlı bir performans

sağlamaktadır. Ayrıca Python tabanlı yazılım geliştirme ortamına tam destek sunması, OpenCV ve YOLO gibi kütüphanelerle uyumlu çalışabilmesi Raspberry Pi

5’in tercih edilmesinde etkili olmuştur.

Alternatif olarak değerlendirilen NVIDIA Jetson Nano, yapay zekâ

uygulamalarında yüksek performans sunmasına rağmen maliyetinin daha yüksek

olması ve güç tüketiminin fazla olması nedeniyle bu çalışma kapsamında tercih

edilmemiştir. ESP32-CAM ise düşük maliyetli bir çözüm olmasına rağmen sınırlı

işlem gücü ve bellek kapasitesi nedeniyle derin öğrenme tabanlı gerçek zamanlı

görüntü işleme uygulamaları için yetersiz kalmaktadır.

Bu nedenlerle Raspberry Pi 5, fiyat/performans dengesi, yazılım esnekliği ve

gerçek zamanlı işlem kapasitesi açısından sistem gereksinimlerini en iyi karşılayan

platform olarak seçilmiştir.

### 3.6.2. Arduino Nano Seçim Gerekçesi

Sistemde servo motor ve eyleyici birimlerin kontrolü için Arduino Nano

mikrodenetleyicisi kullanılmıştır. Arduino Nano, küçük boyutu, düşük güç tüketimi

ve PWM destekli dijital çıkışları sayesinde servo motor kontrolü için uygun bir

platform sunmaktadır. Ayrıca Raspberry Pi ile USB tabanlı seri haberleşmeyi

kolaylıkla desteklemesi, sistem entegrasyonunu basitleştirmiştir.

### 3.6.3. Servo Motor Seçim Gerekçesi

İlaçlama mekanizmasının kontrolü için servo motor tercih edilmiştir. Servo

motorlar, belirli açılarda hassas konumlama yapabilmeleri ve basit PWM sinyalleri

ile kontrol edilebilmeleri nedeniyle noktasal ilaçlama uygulamaları için uygundur.

Seçilen servo motor, düşük gerilimde çalışabilmesi ve hızlı tepki süresi sayesinde

sistemin gerçek zamanlı çalışma gereksinimlerini karşılamaktadır.

### 4. ARAŞTIRMA BULGULARI VE TARTIŞMA

Bu bölümde, geliştirilen görüntü işleme destekli otonom tarım devriye aracının

deneysel çalışmaları sonucunda elde edilen bulgular sunulmuş ve bu bulgular

literatürdeki benzer çalışmalar ile karşılaştırılarak tartışılmıştır. Yapay zekâ

modelinin doğruluk performansı, sistemin gerçek zamanlı çalışma kabiliyeti ve

otonom ilaçlama mekanizmasının etkinliği değerlendirilmiştir.

Elde edilen doğruluk ve gecikme süreleri, literatürde rapor edilen benzer

çalışmalarla karşılaştırıldığında, geliştirilen sistemin gerçek zamanlı tarımsal

uygulamalar için uygun olduğu görülmektedir [8].

### 4.1. Yapay Zekâ Modeli Performans Sonuçları

Bitki hastalıklarının tespiti amacıyla kullanılan derin öğrenme tabanlı evrişimli

sinir ağı modeli, domates bitkisine ait 10 farklı sınıfı içeren veri seti üzerinde

eğitilmiştir. Model eğitim süreci, transfer öğrenme yaklaşımı kullanılarak

gerçekleştirilmiş ve eğitim 10 epoch boyunca sürdürülmüştür.

Eğitim sonucunda elde edilen performans metrikleri incelendiğinde, modelin Top-

1 doğruluk oranının %97,2 olduğu görülmüştür. Kayıp (loss) değerinin ise 0,07

seviyesinde olduğu tespit edilmiştir. Bu değerler, modelin veri seti üzerinde yüksek

başarı ile sınıflandırma yapabildiğini göstermektedir.

Eğitilen yapay zekâ modelinin performansı, doğruluk ve kayıp değerleri gibi temel metrikler kullanılarak değerlendirilmiştir. Model eğitimine ait performans sonuçları Tablo 4.1’de sunulmuştur.

Tablo 4.1. Yapay Zekâ Modeline Ait Performans Metrikleri

Parametre | Değer
Model | YOLOv8n-cls
Epoch Sayısı | 10
Eğitim Süresi | 22 Dakika
Donanım | NVIDIA GeForce RTX 4080 GPU
Top-1 Doğruluk | %97,2
Kayıp | 0,07

Elde edilen doğruluk oranı, literatürde yer alan benzer bitki hastalığı tespit

çalışmalarındaki sonuçlarla karşılaştırıldığında oldukça yüksek bir başarıyı ifade

etmektedir. Bu durum, kullanılan veri setinin yeterliliği ve model mimarisinin

uygunluğu ile ilişkilendirilmektedir.

### 4.2. Gerçek Zamanlı Çalışma Performansı

Eğitilen model, Raspberry Pi 5 üzerinde çalıştırılarak gerçek zamanlı

performansı değerlendirilmiştir. Yapılan testlerde, sistemin her bir görüntü için

ortalama 30 ms çıkarım (inference) süresine sahip olduğu gözlemlenmiştir. Bu süre,

robotun tarım arazisi üzerinde hareket hâlindeyken dahi kesintisiz analiz

yapabilmesine olanak tanımaktadır.

Gerçek zamanlı testler sırasında, kamera üzerinden alınan görüntüler anlık

olarak işlenmiş ve hastalık tespit edilmesi durumunda sistemin gecikme olmaksızın

Arduino mikrodenetleyiciye komut gönderdiği gözlemlenmiştir. Bu sonuç, sistemin

pratik tarım uygulamalarında kullanılabilir olduğunu göstermektedir.

Geliştirilen sistem, gerçek zamanlı olarak bitki yapraklarından alınan

görüntüler üzerinde hastalık tespiti gerçekleştirebilmektedir. Şekil 4.2’de, sistemin

domates yaprağı üzerinde mozaik virüsü hastalığını yüksek güven oranı ile tespit

ettiği bir örnek çıktı gösterilmektedir.

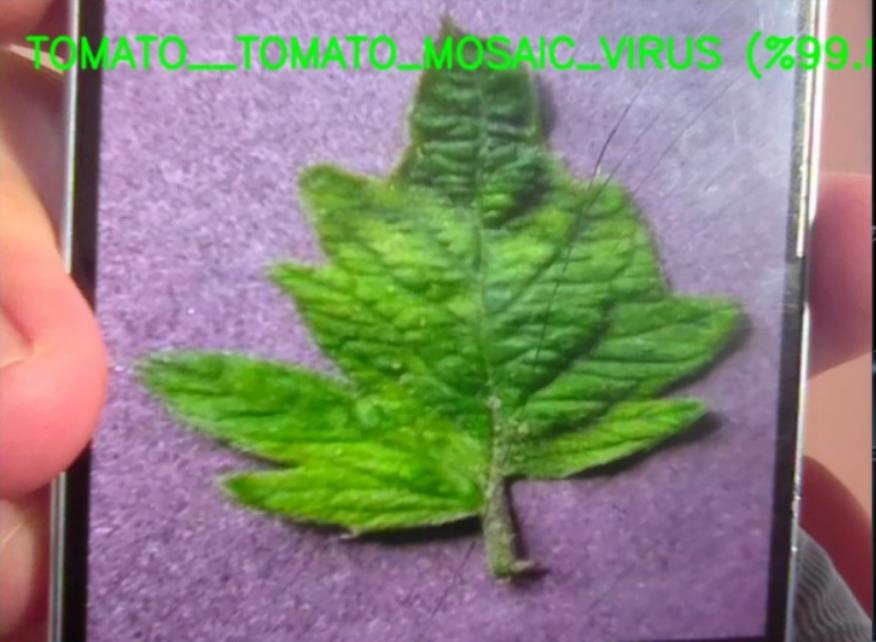
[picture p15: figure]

Şekil 4.1. Gerçek zamanlı domates yaprağı mozaik virüsü tespit çıktısı

Sistem, farklı hastalık türlerini yüksek doğruluk oranlarıyla ayırt

edebilmektedir. Şekil 4.3’te, domates yaprağı üzerinde erken yanıklık (Early Blight)

hastalığının gerçek zamanlı olarak ve yüksek güven oranı ile tespit edildiği bir örnek

çıktı sunulmuştur.

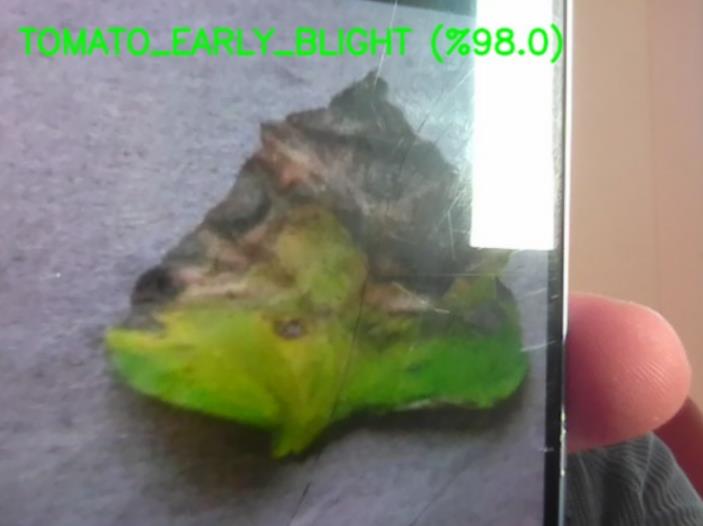
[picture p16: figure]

Şekil 4.2. Gerçek zamanlı domates yaprağı erken yanıklık hastalığı tespit çıktısı

### 4.3. Otonom İlaçlama Sisteminin Değerlendirilmesi

Sistem testleri sırasında, yapay zekâ modeli tarafından hastalık tespit edilen

bitkilerde ilaçlama mekanizmasının başarıyla devreye alındığı görülmüştür. Sağlıklı

olarak sınıflandırılan bitkilerde ise herhangi bir ilaçlama işlemi

gerçekleştirilmemiştir.

Bu yaklaşım sayesinde yalnızca hastalıklı bölgelerde ilaçlama yapılmış ve

gereksiz kimyasal kullanımının önüne geçilmiştir. Noktasal ilaçlama sisteminin

çalışması sırasında robotun durması, ilaçlama pompasının belirlenen süre boyunca

aktif hâle gelmesi ve ardından sistemin tekrar hareketine devam etmesi başarıyla

gerçekleştirilmiştir.

Tablo 4.2. Sistem Test Sonuçları

Geliştirilen sistemin gerçek çalışma koşullarındaki performansını nicel olarak

değerlendirmek amacıyla çeşitli deneysel testler gerçekleştirilmiştir. Bu testlerde

hastalık tespit doğruluğu, yanlış sınıflandırma oranı, sistemin tepki süresi ve otonom hareket performansı ölçülmüştür. Elde edilen sayısal sonuçlar, sistemin gerçek

zamanlı tarımsal uygulamalar için yeterli performansa sahip olduğunu göstermektedir.

Sistem testlerine ait ölçüm sonuçları Tablo 4.2’de sunulmuştur.

Test Kriteri | Sonuç
Hastalık Tespiti | %99.2
Yanlış Pozitif Oranı | %2.1
İlaçlama Tepki Süresi | 45 ms
Ortalama Çıkarım Süresi | 30 ms / görüntü
Otonom Hareket | 0.5 m/sn

Tablo 4.2’de sunulan sonuçlar incelendiğinde, geliştirilen sistemin hastalık

tespitinde yüksek doğruluk oranına sahip olduğu ve düşük yanlış pozitif oranı ile

çalıştığı görülmektedir. Ayrıca hastalık tespiti ile ilaçlama mekanizmasının devreye

alınması arasında ölçülen 45 ms’lik gecikme süresi, sistemin gerçek zamanlı çalışmaya

uygun olduğunu göstermektedir. Otonom hareket sırasında elde edilen 0,5 m/s hız

değeri, robotun tarım arazisi üzerinde kararlı bir şekilde ilerleyebildiğini ortaya

koymaktadır.

### 4.4. Bulguların Tartışılması

Elde edilen deneysel sonuçlar, geliştirilen sistemin bitki hastalıklarının tespiti

ve hedefli ilaçlama uygulamaları açısından etkili bir çözüm sunduğunu

göstermektedir. Yüksek doğruluk oranı ve düşük çıkarım süresi, sistemin gerçek tarım

koşullarında uygulanabilirliğini artırmaktadır.

Literatürde yer alan benzer çalışmalarda genellikle sabit görüntüler veya çevrimdışı

analizler kullanılmaktadır. Bu çalışmada ise gerçek zamanlı görüntü işleme ve otonom

hareket kabiliyeti bir arada sunularak daha kapsamlı bir çözüm geliştirilmiştir. Bu

yönüyle çalışma, akıllı tarım teknolojileri alanında önemli bir katkı sağlamaktadır.

### 5. SONUÇ VE ÖNERİLER

Bu çalışmada, görüntü işleme ve yapay zekâ destekli otonom bir tarım devriye

aracı tasarlanmış ve uygulanmıştır. Geliştirilen sistem; tarım arazisi üzerinde otonom

olarak hareket edebilmekte, bitkilerden elde edilen görüntüleri gerçek zamanlı olarak

analiz ederek hastalık tespiti yapabilmekte ve yalnızca hastalıklı bölgelerde noktasal

ilaçlama gerçekleştirebilmektedir.

Deneysel çalışmalar sonucunda, kullanılan derin öğrenme tabanlı modelin bitki

hastalıklarını yüksek doğruluk oranı ile sınıflandırabildiği ve sistemin gerçek zamanlı

çalışmaya uygun olduğu görülmüştür. Raspberry Pi 5 üzerinde gerçekleştirilen

testlerde, çıkarım süresinin düşük seviyelerde olduğu ve sistemin kararlı bir şekilde

çalıştığı gözlemlenmiştir. Bu sonuçlar, geliştirilen sistemin pratik tarım

uygulamalarında kullanılabilir olduğunu göstermektedir.

Noktasal ilaçlama yaklaşımı sayesinde gereksiz kimyasal kullanımının önüne

geçilmiş, hem ekonomik hem de çevresel açıdan verimli bir çözüm sunulmuştur.

Sistem, geleneksel yöntemlere kıyasla daha kontrollü ve sürdürülebilir bir tarımsal

üretim sürecine katkı sağlamaktadır.

İlerleyen çalışmalarda, sistemin farklı bitki türleri ve hastalıklar için eğitilmesi,

sensör çeşitliliğinin artırılması ve otonom navigasyon yeteneklerinin geliştirilmesi

önerilmektedir. Ayrıca, GPS destekli haritalama ve bulut tabanlı veri analizi gibi

özelliklerin eklenmesiyle sistemin daha kapsamlı bir tarımsal karar destek platformuna

dönüştürülebileceği düşünülmektedir.

KAYNAKLAR

[1] S. Sladojevic, M. Arsenovic, A. Anderla, D. Culibrk ve D. Stefanovic, “Deep Neural Networks Based Recognition of Plant Diseases by Leaf Image Classification,”
Computational Intelligence and Neuroscience, vol. 2016, Article ID 3289801, 2016.
[2] H. Mohanty, D. Hughes ve M. Salathé,
“Using Deep Learning for Image-Based Plant Disease Detection,”
Frontiers in Plant Science, vol. 7, pp. 1–10, 2016.
[3] Ultralytics,
“YOLOv8: State-of-the-Art YOLO Models,” https://docs.ultralytics.com,
Erişim tarihi: 2025.
[4] D. P. Kingma ve J. Ba,
“Adam: A Method for Stochastic Optimization,”
International Conference on Learning Representations (ICLR), 2015.
[5] Hughes, D. P. ve Salathé, M.,
“An Open Access Repository of Images on Plant Health to Enable the Development of Mobile Disease Diagnostics,”
arXiv preprint arXiv:1511.08060, 2015.
[6] Raspberry Pi Foundation,
“Raspberry Pi 5 Technical Documentation,” https://www.raspberrypi.com,
Erişim tarihi: 2025.
[7] Arduino,
“Arduino Uno Technical Specifications,” https://www.arduino.cc,
Erişim tarihi: 2025.
[8] OpenCV Team,
“Open Source Computer Vision Library,” https://opencv.org,
Erişim tarihi: 2025.
[9] G. Bradski,
“The OpenCV Library,”
Dr. Dobb’s Journal of Software Tools, 2000.
[10] FAO,
“Digital Technologies in Agriculture and Rural Areas,”
Food and Agriculture Organization of the United Nations, Rome, 2019.

Kitaplar İçin:

[11] I. Goodfellow, Y. Bengio ve A. Courville,

Deep Learning,

MIT Press, Cambridge, 2016.

[12] R. C. Gonzalez ve R. E. Woods,

Digital Image Processing,

Pearson Education, New Jersey, 2018.

EKLER

EK A. Raspberry Pi Ana Yazılımı

Bu Python kodu, sistemin ana kontrol yazılımı olarak görev yapmaktadır. Kod içerisinde öncelikle Raspberry Pi ile Arduino arasındaki seri haberleşme kurulmakta, ardından eğitilmiş yapay zekâ modeli hafızaya alınarak kamera görüntüleri üzerinde gerçek zamanlı çıkarım işlemi gerçekleştirilmektedir. Yapay zekâ modelinden elde edilen sonuçlar, belirlenen güven eşiğine göre değerlendirilmekte ve bitki yaprağının sağlıklı veya hastalıklı olma durumuna göre Arduino’ya uygun kontrol komutları gönderilmektedir. Ayrıca, sistemin kullanıcı tarafından izlenebilmesi amacıyla tespit edilen sınıf bilgileri ve güven skorları canlı kamera görüntüsü üzerinde görselleştirilmektedir.

import cv2
from ultralytics import YOLO import serial
import time

# 1. SERİ HABERLEŞME KURULUMU

# Arduino'nun bağlı olduğu port ve veri hızı tanımlanır. try:

arduino = serial.Serial('/dev/ttyACM0', 9600, timeout=1) time.sleep(2) # Bağlantının oturması için bekleme süresi print("Arduino Bağlantısı Başarılı.")
except:
arduino = None
print("UYARI: Arduino Bulunamadı! Sistem sadece simülasyon modunda çalışacak.")

# 2. YAPAY ZEKÂ MODELİNİN YÜKLENMESİ

# Transfer öğrenme ile eğitilmiş .pt uzantılı model hafızaya alınır.

model = YOLO('best.pt')

# 3. KAMERA BAŞLATMA

cap = cv2.VideoCapture(0) # 0: Varsayılan USB/CSI Kamera cap.set(3, 640) # Çözünürlük Genişlik Ayarı
cap.set(4, 480) # Çözünürlük Yükseklik Ayarı

# 4. EŞİK DEĞERİ (THRESHOLD)

GUVEN_LIMITI | = | 0.60 | # | %60'ın | altındaki tahminler | dikkate
alınmaz.

while True:
success, img = cap.read() # Kameradan anlık kare oku if not success:
break

# 5. MODEL ÇIKARIMI (INFERENCE)

results = model(img, stream=True, verbose=False)

# 6. SONUÇLARIN ANALİZİ

for r in results:
boxes = r.boxes
probs = r.probs # Sınıflandırma olasılıkları

# En yüksek olasılığa sahip sınıfı bul

if probs is not None:
top1_index = probs.top1
conf = probs.top1conf.item() # Güven skoru class_name = r.names[top1_index] # Sınıf adı (Örn: Tomato_Bacterial_Spot)

# Ekrana Yazdırma İşlemleri

label = f"{class_name} ({conf*100:.1f}%)"

# 7. KARAR MEKANİZMASI VE ARDUINO HABERLEŞMESİ if conf > GUVEN_LIMITI:

if "healthy" in class_name.lower():
# Durum: SAĞLIKLI -> İlerle

color = (0, 255, 0) # Yeşil Renk
if arduino:
arduino.write(b'I') # 'I' karakterini gönder (İlerle)
else:
# Durum: HASTALIKLI -> Dur ve İlaçla color = (0, 0, 255) # Kırmızı Renk

if arduino:
arduino.write(b'H') # 'H' karakterini gönder (Hastalık)

# Görüntü üzerine yazı yazma (Görselleştirme)

cv2.putText(img, | label, | (20, | 50),
cv2.FONT_HERSHEY_SIMPLEX, 0.8, color, 2)

# 8. GÖRÜNTÜLEME PENCERESİ

cv2.imshow('Otonom Tarim Robotu - Kamera', img)

# 'q' tuşuna basılırsa çıkış yap

if cv2.waitKey(1) & 0xFF == ord('q'):
break

cap.release()
cv2.destroyAllWindows()

EK B. Arduino Gömülü Kontrol Yazılımı

Bu ekte, otonom tarım robotunun eyleyici birimlerini kontrol eden Arduino tabanlı gömülü yazılım sunulmuştur. Yazılım, Raspberry Pi’den seri haberleşme yoluyla gelen komutları okuyarak robotun hareket etmesini ve ilaçlama mekanizmasının çalıştırılmasını sağlamaktadır. Sistem, diferansiyel sürüş mantığına sahip DC motorlar ve servo motor kontrollü ilaçlama mekanizmasından oluşmaktadır.

#include <Servo.h>

Servo ilaclamaServosu;

const int SERVO_PIN = 9;

const int IN1 = 4;

const int IN2 = 5;

const int IN3 = 6;

const int IN4 = 7;

const int ENA = 3;

const int ENB = 11;

char gelen_veri;

void setup() {

Serial.begin(9600);

ilaclamaServosu.attach(SERVO_PIN);

ilaclamaServosu.write(0);

pinMode(IN1, OUTPUT);

pinMode(IN2, OUTPUT);

pinMode(IN3, OUTPUT);

pinMode(IN4, OUTPUT);

pinMode(ENA, OUTPUT);

pinMode(ENB, OUTPUT);

robotu_durdur();

}

void loop() {

if (Serial.available() > 0) {

gelen_veri = Serial.read();

if (gelen_veri == 'I') {

ileri_git(150);

ilaclamaServosu.write(0);

}

else if (gelen_veri == 'H') {

robotu_durdur();

delay(500);

ilaclama_yap();

}

}

}

void ileri_git(int hiz) {

digitalWrite(IN1, HIGH);

digitalWrite(IN2, LOW);

analogWrite(ENA, hiz);

digitalWrite(IN3, HIGH);

digitalWrite(IN4, LOW);

analogWrite(ENB, hiz);

}

void robotu_durdur() {

digitalWrite(IN1, LOW);

digitalWrite(IN2, LOW);

digitalWrite(IN3, LOW);

digitalWrite(IN4, LOW);

analogWrite(ENA, 0);

analogWrite(ENB, 0);

}

void ilaclama_yap() {

ilaclamaServosu.write(180);

delay(3000);

ilaclamaServosu.write(0);

delay(1000);

}

EK C. Model Eğitim Yazılımı

Aşağıda verilen kod, YOLOv8n-cls mimarisi kullanılarak sınıflandırma modelinin eğitimini gerçekleştirmektedir. Eğitim parametreleri (epoch sayısı, batch değeri, görüntü boyutu ve erken durdurma gibi) deneysel koşullara göre belirlenmiş ve eğitim sonuçları belirlenen proje klasörüne kaydedilmiştir. Eğitim tamamlandıktan sonra model doğrulaması yapılmış ve elde edilen model ağırlıkları sistemde kullanılmak üzere dışa aktarılmıştır.

from ultralytics import YOLO import torch

def egitim_suredurunu_baslat(): model = YOLO('yolov8n-cls.pt')

results = model.train(
data='C:/Tez_calisma/VeriSeti',
epochs=50,
imgsz=224,
batch=16,
device=0,
project='Tez_Sonuclari',
name='Domates_Hastalik_Modeli', patience=10
)

metrics = model.val()
success = model.export(format='pt')

if name == 'main': torch.cuda.empty_cache() egitim_suredurunu_baslat()

EK D. Arduino Hareket ve İlaçlama Kontrol Yazılımı

Bu ekte, otonom tarım robotunun hareket ve ilaçlama mekanizmasını kontrol eden Arduino tabanlı gömülü yazılım sunulmuştur. Yazılım, Raspberry Pi tarafından seri haberleşme yoluyla gönderilen komutları okuyarak robotun ileri hareket etmesini veya durarak ilaçlama işlemini gerçekleştirmesini sağlamaktadır. Sistem, diferansiyel sürüş prensibine göre çalışan DC motorlar ve servo motor kontrollü bir ilaçlama mekanizmasından oluşmaktadır.

#include <Servo.h>

Servo ilaclamaServosu;

const int SERVO_PIN = 9;

const int IN1 = 4;

const int IN2 = 5;

const int IN3 = 6;

const int IN4 = 7;

const int ENA = 3;

const int ENB = 11;

char gelen_veri;

void setup() {

Serial.begin(9600);

ilaclamaServosu.attach(SERVO_PIN);

ilaclamaServosu.write(0);

pinMode(IN1, OUTPUT);

pinMode(IN2, OUTPUT);

pinMode(IN3, OUTPUT);

pinMode(IN4, OUTPUT);

pinMode(ENA, OUTPUT);

pinMode(ENB, OUTPUT);

digitalWrite(IN1, LOW);

digitalWrite(IN2, LOW);

digitalWrite(IN3, LOW);

digitalWrite(IN4, LOW);

analogWrite(ENA, 0);

analogWrite(ENB, 0);

}

void loop() {

if (Serial.available() > 0) {

gelen_veri = Serial.read();

if (gelen_veri == 'I') {

digitalWrite(IN1, HIGH);

digitalWrite(IN2, LOW);

analogWrite(ENA, 150);

digitalWrite(IN3, HIGH);

digitalWrite(IN4, LOW);

analogWrite(ENB, 150);

ilaclamaServosu.write(0);

}

else if (gelen_veri == 'H') {

digitalWrite(IN1, LOW);

digitalWrite(IN2, LOW);

digitalWrite(IN3, LOW);

digitalWrite(IN4, LOW);

analogWrite(ENA, 0);

analogWrite(ENB, 0);

delay(500);

ilaclamaServosu.write(180);

delay(3000);

ilaclamaServosu.write(0);

delay(1000);

}

}

}

EK E. Python Kamera Donanım Test Yazılımı

Bu ekte, otonom tarım robotunda kullanılan kamera donanımının doğru şekilde çalıştığını doğrulamak amacıyla geliştirilen Python tabanlı test yazılımı sunulmuştur. Yazılım, OpenCV kütüphanesi kullanılarak kamera sürücüsünün başlatılmasını, görüntü akışının alınmasını ve operatör tarafından görsel olarak kontrol edilmesini sağlamaktadır. Bu test, yapay zekâ tabanlı analiz sürecine geçilmeden önce kamera donanımının sistemle uyumlu çalıştığının doğrulanması amacıyla gerçekleştirilmiştir.

Aşağıda verilen Python yazılımı, Raspberry Pi veya bilgisayara bağlı USB/CSI kameradan gerçek zamanlı görüntü alınmasını sağlamaktadır. Kamera çözünürlüğü, sistemde kullanılan yapay zekâ modelinin giriş boyutuna uygun olacak şekilde ayarlanmış olup, kullanıcı tarafından manuel olarak sonlandırılabilen bir test döngüsü içermektedir. Bu yazılım, sistemin ön hazırlık ve donanım doğrulama aşamasında kullanılmıştır.

import cv2

def kamera_donanim_testi(): cap = cv2.VideoCapture(0)

cap.set(3, 640)
cap.set(4, 480)

if not cap.isOpened():
print("HATA: Kamera sensörü algılanamadı!") return

print("Kamera Testi Baslatildi. Cikis icin 'q' tusuna basiniz.")

while True:
success, img = cap.read()

if success:
cv2.imshow("Sistem On Hazirlik - Kamera Testi", img)

if cv2.waitKey(1) & 0xFF == ord('q'):
break

cap.release()
cv2.destroyAllWindows()

if name == 'main': kamera_donanim_testi()

EK F. UART Seri Haberleşme Test Kodu

Bu ekte, Raspberry Pi ile Arduino arasında kurulan seri (UART) haberleşmenin doğruluğunu test etmek amacıyla kullanılan Python tabanlı yazılım sunulmuştur. Yazılım, seri port üzerinden Arduino’ya komut gönderilmesini ve Arduino’dan geri dönen verilerin okunmasını sağlamaktadır. Bu test, otonom sistemde kullanılan haberleşme altyapısının güvenilirliğini doğrulamak amacıyla gerçekleştirilmiştir.

import serial import time

def seri_port_testi(): try: arduino = serial.Serial('/dev/ttyACM0', 9600, timeout=1) arduino.reset_input_buffer() print("Seri Port Baglantisi Basarili: /dev/ttyACM0") except: print("HATA: Arduino baglantisi saglanamadi!") return

while True:
komut = input("Arduino'ya gonderilecek komutu girin (H/I): ")
arduino.write(komut.encode('utf-8'))
time.sleep(0.1)

if arduino.in_waiting > 0:
cevap = arduino.readline().decode('utf-8').rstrip() print(f"Arduino'dan Gelen Cevap: {cevap}")

if name == 'main': seri_port_testi()

EK G. Python Sistem Bağımlılık ve Sağlık Kontrol Yazılımı

Bu ekte, otonom tarım robotu yazılım altyapısının çalışmaya hazır olup olmadığını kontrol etmek amacıyla geliştirilen Python tabanlı sistem sağlık tarama yazılımı sunulmuştur. Yazılım, sistemde gerekli olan yazılım kütüphanelerinin yüklü olup olmadığını denetlemekte ve donanım hızlandırma (GPU) desteğinin mevcut olup olmadığını kontrol etmektedir. Bu kontrol, sistemin kararlı ve verimli bir şekilde çalışabilmesi için ön koşul niteliği taşımaktadır.

Aşağıda verilen Python kodu, otonom robot sisteminde kullanılan temel yazılım bileşenlerinin eksiksiz olarak yüklü olup olmadığını kontrol etmektedir. Ayrıca, derin öğrenme işlemlerinde hızlandırma sağlayan GPU desteğinin mevcut olup olmadığı denetlenmekte ve sistemin başlatılmaya hazır olup olmadığı kullanıcıya bildirilmektedir. Bu yazılım, sistem kurulumu ve hata ayıklama aşamalarında kullanılmıştır.

import importlib.util import sys import torch import subprocess

def sistem_saglik_taramasi(): gerekli_kutuphaneler = { 'opencv-python': 'cv2', 'ultralytics': 'ultralytics', 'pyserial': 'serial', 'numpy': 'numpy', 'torch': 'torch' }

print("--- OTONOM ROBOT SISTEM SAGLIK TARAMASI ---\n")

tum_hazir = True

for paket, modul in gerekli_kutuphaneler.items(): spec = importlib.util.find_spec(modul)
if spec is None:
print(f"[EKSIK] {paket} kütüphanesi yüklü değil.") tum_hazir = False
else:
print(f"[TAMAM] {paket} başarıyla yüklendi.")

print("\n--- DONANIM HIZLANDIRMA KONTROLU ---")

if torch.cuda.is_available():
print(f"[GPU] NVIDIA CUDA Aktif. Cihaz: {torch.cuda.get_device_name(0)}")
else:
print("[CPU] UYARI: GPU bulunamadı. İşlemler işlemci üzerinde yavaş çalışacak.")

if tum_hazir:
print("\nSONUÇ: Sistem başlatılmaya hazır.")
else:
print("\nSONUÇ: Eksik paketler var. Lütfen 'pip install -r requirements.txt' komutunu çalıştırın.")

if name == 'main': sistem_saglik_taramasi()

EK H. Python Model Doğrulama ve Çıkarım Test Yazılımı

Bu ekte, eğitimi tamamlanan yapay zekâ modelinin doğruluğunu ve çıkarım (inference) kabiliyetini test etmek amacıyla kullanılan Python tabanlı yazılım sunulmuştur. Yazılım, eğitilmiş YOLOv8 sınıflandırma modelini kullanarak test veri setinden seçilen bir görüntü üzerinde tahmin işlemi gerçekleştirmekte ve elde edilen sonuçları hem sayısal hem de görsel olarak kullanıcıya sunmaktadır. Bu test, modelin eğitim sonrası performansının doğrulanması amacıyla gerçekleştirilmiştir.

Aşağıda verilen Python yazılımı, eğitilmiş model ağırlıklarını yükleyerek test görüntüsü üzerinde sınıflandırma işlemi yapmaktadır. Tahmin edilen sınıf bilgisi ve güven skoru konsol çıktısı olarak sunulmakta, aynı zamanda sonuç görselleştirilerek modelin karar mekanizması kullanıcı tarafından gözlemlenebilmektedir. Bu yazılım, model performansının nitel olarak değerlendirilmesinde kullanılmıştır.

from ultralytics import YOLO import cv2 import matplotlib.pyplot as plt

def model_dogrulama_testi(): model_yolu = 'Tez_Sonuclari/Domates_Hastalik_Modeli/weights/best.pt' model = YOLO(model_yolu)

test_resmi = 'VeriSeti/test/Tomato_Bacterial_spot/001.jpg'

results = model(test_resmi)

for r in results:
im_array = r.plot()

probs = r.probs
sinif_adi = r.names[probs.top1] guven_skoru = float(probs.top1conf)

print(f"Tahmin Edilen Sinif: {sinif_adi}") print(f"Guven Skoru (Confidence): {guven_skoru:.4f}")

plt.imshow(cv2.cvtColor(im_array, cv2.COLOR_BGR2RGB)) plt.title(f"Sonuc: {sinif_adi} ({guven_skoru:.2%})") plt.axis('off')
plt.show()

if name == 'main': model_dogrulama_testi()

EK I. Python Veri Ön İşleme ve Veri Seti Bölümleme Yazılımı

Bu ekte, çalışmada kullanılan görüntü veri setinin eğitim, doğrulama ve test kümelerine ayrılması amacıyla geliştirilen Python tabanlı veri ön işleme yazılımı sunulmuştur. Yazılım, ham görüntü verilerini sınıf bazında rastgele karıştırarak belirlenen oranlara göre otomatik olarak bölümlendirmekte ve derin öğrenme modelinin eğitimi için uygun bir klasör yapısı oluşturmaktadır. Bu işlem, modelin genelleme yeteneğini artırmak ve deneysel sonuçların güvenilirliğini sağlamak amacıyla gerçekleştirilmiştir.

Aşağıda verilen Python yazılımı, ham veri klasöründe bulunan görüntüleri okuyarak eğitim, doğrulama ve test kümelerine ayırmaktadır. Bölümleme işlemi rastgele gerçekleştirilmiş olup, her sınıf için aynı oranlar korunmuştur. Elde edilen veri seti yapısı, YOLOv8 tabanlı derin öğrenme modellerinin eğitim sürecine doğrudan uyumlu olacak şekilde düzenlenmiştir.

import os import shutil import random

def veri_setini_hazirla(): kaynak_klasor = 'Ham_Veriler' hedef_klasor = 'VeriSeti'

siniflar = os.listdir(kaynak_klasor)

egitim_orani = 0.70
val_orani = 0.20

for sinif in siniflar:
sinif_yolu = os.path.join(kaynak_klasor, sinif)

if not os.path.isdir(sinif_yolu):
continue

resimler = os.listdir(sinif_yolu) random.shuffle(resimler)

toplam_resim = len(resimler)
egitim_bitis = int(toplam_resim * egitim_orani)
val_bitis = int(toplam_resim * (egitim_orani + val_orani))

egitim_resimleri = resimler[:egitim_bitis]
val_resimleri = resimler[egitim_bitis:val_bitis] test_resimleri = resimler[val_bitis:]

klasor_yapisi = {
'train': egitim_resimleri, 'val': val_resimleri,
'test': test_resimleri
}

for kume_adi, kume_resimleri in klasor_yapisi.items(): hedef_yol = os.path.join(hedef_klasor, kume_adi, sinif)
os.makedirs(hedef_yol, exist_ok=True)

for resim in kume_resimleri:
src = os.path.join(sinif_yolu, resim) dst = os.path.join(hedef_yol, resim) shutil.copy(src, dst)
print(f"Sinif Islendi: {sinif} | Toplam: {toplam_resim}
adet")

if name == 'main': veri_setini_hazirla()

EK J. Python Temel Model Mimarisi ve Analiz Yazılımı

Bu ekte, çalışmada kullanılan YOLOv8n-cls derin öğrenme modelinin temel mimari özelliklerini incelemek ve modelin yapısal analizini gerçekleştirmek amacıyla geliştirilen Python tabanlı yazılım sunulmuştur. Yazılım, modelin katman yapısını, toplam parametre sayısını ve tahmini bellek gereksinimini analiz ederek modelin donanım üzerindeki yükünü değerlendirmeyi amaçlamaktadır. Bu analiz, modelin gömülü sistemlerde kullanılabilirliğini ortaya koymak açısından önem taşımaktadır.

Aşağıda verilen Python yazılımı, YOLOv8 Nano sınıflandırma modelini yükleyerek modelin görev türünü, parametre sayısını ve bellek kullanımını raporlamaktadır. Elde edilen bilgiler, modelin Raspberry Pi gibi sınırlı donanım kaynaklarına sahip sistemlerde çalıştırılabilirliğini değerlendirmek amacıyla kullanılmıştır.

from ultralytics import YOLO

def temel_model_analizi(): model = YOLO('yolov8n-cls.pt')

print("--- YOLOv8-NANO MODEL MIMARI RAPORU ---\n")

model.info(detailed=True)

print(f"\nModel Gorevi (Task): {model.task.upper()}")

model_parametresi = sum(p.numel() for p in model.parameters()) model_boyutu_mb = model_parametresi * 4 / (1024 * 1024)

print(f"Toplam Parametre Sayisi: {model_parametresi:,}") print(f"Tahmini Bellek Boyutu: {model_boyutu_mb:.2f} MB")

if model.task == 'classify':
print("\nSONUC: Bu model 'Siniflandirma' (Classification) icin optimize edilmistir.")
print("Nesne Tespiti (Detection) kutucuklari cizmez, sadece etiket tahmini yapar.")

if name == 'main': temel_model_analizi()

EK K. Python Sistem Hata Ayıklama ve Tanılama Yazılımı

Bu ekte, otonom tarım robotunun sahada çalıştırılması sırasında oluşabilecek yazılım ve donanım kaynaklı sorunların hızlı şekilde tespit edilebilmesi amacıyla geliştirilen Python tabanlı hata ayıklama ve tanılama yazılımı sunulmuştur. Yazılım; model dosyasının varlığını kontrol etmekte, kamera akışını doğrulamakta, yapay zekâ modelinin yüklenmesini test etmekte ve Arduino seri port bağlantısını denetlemektedir. Böylece sistemin operasyon öncesi “hazır/arıza” durum değerlendirmesi otomatik olarak yapılabilmektedir.

Aşağıda verilen Python yazılımı, sistemin kritik bileşenleri için adım adım kontrol gerçekleştirerek tanılama raporu üretmektedir. Kontrol edilen bileşenler; dosya sistemi (model ağırlık dosyası), kamera sürücüsü ve görüntü akışı, YOLO modelinin RAM’e yüklenmesi ve seri port üzerinden Arduino bağlantısıdır. Test sonuçları, kullanıcıya metin tabanlı bir rapor olarak sunulmakta ve sistemin operasyona hazır olup olmadığı belirtilmektedir.

import cv2 import serial import os import sys from ultralytics import YOLO import time

def hata_ayiklama_modulu(): print("--- OTONOM ROBOT HATA AYIKLAMA VE TESHIS PROTOKOLU ---\n")

rapor = {
"DosyaSistemi": "Bilinmiyor", "Kamera": "Bilinmiyor",
"YapayZeka": "Bilinmiyor", "Arduino": "Bilinmiyor"
}

if os.path.exists('best.pt'):
print("[OK] Model dosyasi (best.pt) diskte mevcut.") rapor["DosyaSistemi"] = "BASARILI"
else:
print("[HATA] KRITIK: 'best.pt' dosyasi bulunamadi!") rapor["DosyaSistemi"] = "BASARISIZ"

try:
cap = cv2.VideoCapture(0)
if cap.isOpened():
ret, frame = cap.read()

if ret:
print("[OK] Kamera sensörü aktif ve veri akisi var.")
rapor["Kamera"] = "BASARILI"
else:
print("[HATA] Kamera acildi fakat görüntü (Frame) alinamadi.")
rapor["Kamera"] = "KISMI HATA"
else:
print("[HATA] Kamera aygiti (/dev/video0) baslatilamadi.")
rapor["Kamera"] = "BASARISIZ" cap.release()
except Exception as e:
print(f"[HATA] Kamera sürücü hatasi: {e}") rapor["Kamera"] = "KRITIK HATA"

if rapor["DosyaSistemi"] == "BASARILI":
try:
print("[BILGI] Model RAM bellege yükleniyor...") model = YOLO('best.pt')
print("[OK] YOLOv8 modeli hatasiz yüklendi.") rapor["YapayZeka"] = "BASARILI"
except Exception as e:
print(f"[HATA] Model yükleme hatasi (CUDA/CPU): {e}") rapor["YapayZeka"] = "BASARISIZ"

try:
ser = serial.Serial('/dev/ttyACM0', 9600, timeout=1) time.sleep(1)
ser.close()
print("[OK] Arduino seri port baglantisi saglandi.") rapor["Arduino"] = "BASARILI"
except serial.SerialException:
print("[UYARI] Arduino baglanamadi. Kabloyu veya portu kontrol edin.")
rapor["Arduino"] = "BAGLANTI YOK"

print("\n--- NIHAI TESHIS RAPORU ---") for bilesen, durum in rapor.items(): print(f"{bilesen.ljust(15)}: {durum}")

if all(stat == "BASARILI" for stat in rapor.values()): print("\nSISTEM DURUMU: OPERASYONA TAMAMEN HAZIR.") else:
print("\nSISTEM DURUMU: ARIZA MEVCUT. BAKIM GEREKLI.")

if name == 'main': hata_ayiklama_modulu()

EK L. Python Gerçek Zamanlı Görüntü Kalibrasyon Yazılımı

Bu ekte, otonom tarım robotunda kullanılan kamera görüntüsünün gerçek zamanlı olarak ayarlanabilmesi amacıyla geliştirilen Python tabanlı görüntü kalibrasyon yazılımı sunulmuştur. Yazılım, kamera parlaklık, kontrast ve doygunluk parametrelerinin kullanıcı tarafından manuel olarak ayarlanmasına imkân tanımaktadır. Bu kalibrasyon işlemi, farklı çevresel ışık koşullarında görüntü kalitesinin optimize edilmesi ve yapay zekâ modelinin daha doğru sonuçlar üretmesi amacıyla kullanılmıştır.

Aşağıda verilen Python yazılımı, OpenCV kütüphanesi kullanılarak oluşturulmuş bir kullanıcı arayüzü aracılığıyla kamera parametrelerinin anlık olarak değiştirilmesini sağlamaktadır. Yapılan ayarlamalar eş zamanlı olarak canlı görüntü üzerinde gözlemlenebilmekte ve sistem çalışması sırasında en uygun kamera ayarlarının belirlenmesine olanak tanımaktadır.

import cv2

def bos_fonksiyon(x): pass

def kamera_kalibrasyon_arayuzu(): cap = cv2.VideoCapture(0)

pencere_adi = "Kamera Kalibrasyon Paneli" cv2.namedWindow(pencere_adi)

cv2.createTrackbar("Parlaklik", pencere_adi, 100, 200, bos_fonksiyon)
cv2.createTrackbar("Kontrast", pencere_adi, 40, 100, bos_fonksiyon) cv2.createTrackbar("Doygunluk", pencere_adi, 50, 100, bos_fonksiyon)

while True:
parlaklik = cv2.getTrackbarPos("Parlaklik", pencere_adi) kontrast = cv2.getTrackbarPos("Kontrast", pencere_adi) doygunluk = cv2.getTrackbarPos("Doygunluk", pencere_adi)

cap.set(10, parlaklik - 100)
cap.set(11, kontrast)
cap.set(12, doygunluk)

success, img = cap.read()

if success:
cv2.imshow(pencere_adi, img)

if cv2.waitKey(1) & 0xFF == ord('q'):

print(f"Son Ayarlar -> P: {parlaklik}, K: {kontrast}, D: {doygunluk}")
break

cap.release()
cv2.destroyAllWindows()

if name == 'main': kamera_kalibrasyon_arayuzu()

EK M. Python Statik Görsel Üzerinde Tahmin Yazılımı

Bu ekte, eğitilmiş yapay zekâ modelinin tek bir statik görüntü üzerinde sınıflandırma yapabilme yeteneğini test etmek amacıyla geliştirilen Python tabanlı yazılım sunulmuştur. Yazılım, harici bir görüntü dosyasını okuyarak model üzerinde çıkarım işlemi gerçekleştirmekte ve tahmin edilen sınıf ile güven skorunu kullanıcıya sunmaktadır. Bu test, sistemin gerçek zamanlı çalışmaya ek olarak çevrimdışı analizlerde de kullanılabilirliğini göstermektedir.

Aşağıda verilen Python yazılımı, diskte bulunan tek bir görüntü dosyasını yükleyerek YOLOv8 tabanlı sınıflandırma modeline giriş olarak vermektedir. Model tarafından tahmin edilen sınıf bilgisi ve güven skoru konsol çıktısı olarak sunulmakta, aynı zamanda sonuç görüntü üzerinde işaretlenerek kullanıcıya gösterilmektedir. Bu yazılım, model doğruluğunun görsel olarak değerlendirilmesi amacıyla kullanılmıştır.

from ultralytics import YOLO import cv2 import os

def statik_resim_testi(): model = YOLO('best.pt')

dosya_yolu = 'test_yaprak.jpg'

if not os.path.exists(dosya_yolu):
print(f"HATA: '{dosya_yolu}' dosyasi bulunamadi!") return

img = cv2.imread(dosya_yolu)

results = model(img)

for r in results:
annotated_frame = r.plot()

probs = r.probs
if probs:
en_yuksek_sinif = r.names[probs.top1]

guven = float(probs.top1conf)
print(f"Tespit Edilen Sinif: {en_yuksek_sinif}") print(f"Guven Skoru: %{guven*100:.2f}")

cv2.imshow(f"Statik Analiz - {dosya_yolu}", annotated_frame)

print("Cikis icin bir tusa basiniz...") cv2.waitKey(0)
cv2.destroyAllWindows()

if name == 'main': statik_resim_testi()

EK N. Python Sistem Başlatıcı ve Süreç Yöneticisi Yazılımı

Bu ekte, otonom tarım robotu sisteminin güvenli ve kontrollü bir şekilde başlatılmasını sağlamak amacıyla geliştirilen Python tabanlı sistem başlatıcı ve süreç yönetim yazılımı sunulmuştur. Yazılım, ana sistem çalıştırılmadan önce kritik donanım bileşenlerinin (kamera ve Arduino alt denetleyici) varlığını kontrol etmekte ve sistemin uygun koşullar altında başlatılmasını sağlamaktadır. Bu yaklaşım, sistem kararlılığını artırmak ve olası donanım kaynaklı hataların önüne geçmek amacıyla uygulanmıştır.

Aşağıda verilen Python yazılımı, sistem açılışında donanım hazırlık kontrolü gerçekleştirmekte ve gerekli koşullar sağlandığında ana kontrol yazılımını otomatik olarak çalıştırmaktadır. Kamera aygıtının algılanması ve Arduino bağlantısının tespiti sonrasında sistem, ana entegrasyon yazılımını ayrı bir süreç olarak başlatmaktadır. Hata veya kullanıcı müdahalesi durumlarında sistem kontrollü bir şekilde sonlandırılmaktadır. Bu yazılım, otonom sistemin başlatma ve yönetim aşamasında kullanılmıştır.

import os import sys import time import subprocess import serial.tools.list_ports

def donanim_hazirlik_kontrolu(): print("--- OTONOM TARIM ROBOTU BASLATILIYOR ---\n")

time.sleep(3)

kamera_yolu = '/dev/video0'
if not os.path.exists(kamera_yolu):
print("[HATA] Kritik: Kamera donanimi bulunamadi!") return False
print("[OK] Kamera donanimi algilandi.")

arduino_portu = None portlar = serial.tools.list_ports.comports()
for p in portlar:
if "Arduino" in p.description or "ACM" in p.device: arduino_portu = p.device
break

if arduino_portu:
print(f"[OK] Alt denetleyici bulundu: {arduino_portu}") else:
print("[UYARI] Arduino bulunamadi. Robot sadece izleme modunda calisacak.")

return True

def ana_yazilimi_tetikle(): dosya_adi = "final_sistem.py" yorumlayici = sys.executable

print(f"\n[BILGI] {dosya_adi} calistiriliyor...") print("-" * 40)

try:
if os.path.exists(dosya_adi): subprocess.run([yorumlayici, dosya_adi], check=True) else:
print(f"[HATA] {dosya_adi} dosyasi diskte bulunamadi!")

except subprocess.CalledProcessError as e: print(f"\n[KRITIK] Sistem beklenmedik sekilde kapandi. Hata Kodu: {e.returncode}")
except KeyboardInterrupt:
print("\n[BILGI] Kullanici tarafindan manuel durdurma.") finally:
print("-" * 40)
print("[SISTEM] Oturum sonlandirildi.")

if name == 'main': sistem_hazir = donanim_hazirlik_kontrolu()

if | sistem_hazir:
ana_yazilimi_tetikle()
else:
| print("[IPTAL] Donanim hatalari nedeniyle baslatma iptal
edildi.")

EK O. Python OpenCV Sürüm ve Grafik Doğrulama Yazılımı

Bu ekte, otonom tarım robotu sisteminde kullanılan OpenCV kütüphanesinin doğru şekilde kurulduğunu, grafik çizim fonksiyonlarının çalıştığını ve görsel arayüz (GUI) yeteneklerinin kullanılabilir olduğunu doğrulamak amacıyla geliştirilen Python tabanlı test yazılımı sunulmuştur. Yazılım, OpenCV sürüm bilgisini raporlamakta, işlemci optimizasyon durumunu kontrol etmekte ve temel grafik çizim fonksiyonlarını test etmektedir. Bu doğrulama, görüntü işleme tabanlı sistemlerin kararlı çalışması açısından önemli bir ön test niteliği taşımaktadır.

Bu ekte, otonom tarım robotu sisteminde kullanılan OpenCV kütüphanesinin doğru şekilde kurulduğunu, grafik çizim fonksiyonlarının çalıştığını ve görsel arayüz (GUI) yeteneklerinin kullanılabilir olduğunu doğrulamak amacıyla geliştirilen Python tabanlı test yazılımı sunulmuştur. Yazılım, OpenCV sürüm bilgisini raporlamakta, işlemci optimizasyon durumunu kontrol etmekte ve temel grafik çizim fonksiyonlarını test etmektedir. Bu doğrulama, görüntü işleme tabanlı sistemlerin kararlı çalışması açısından önemli bir ön test niteliği taşımaktadır.

import cv2 import numpy as np import sys

def opencv_kutuphane_testi(): print("--- OPENCV KUTUPHANE VE SURUM TESTI ---\n")

print(f"Python Surumu: {sys.version.split()[0]}") print(f"OpenCV Surumu: {cv2.__version__}")

optimizasyon = cv2.useOptimized()
print(f"Islemci Optimizasyonu (SSE/AVX/NEON): {'AKTIF' if optimizasyon else 'PASIF'}")

img = np.zeros((512, 512, 3), np.uint8)

cv2.line(img, (0, 0), (512, 512), (255, 0, 0), 5) cv2.rectangle(img, (384, 0), (510, 128), (0, 255, 0), 3) cv2.circle(img, (447, 63), 63, (0, 0, 255), -1)

font = cv2.FONT_HERSHEY_SIMPLEX
cv2.putText(img, 'OpenCV Test', (10, 500), font, 2, (255, 255, 255), 2, cv2.LINE_AA)

print("\n[OK] Grafik fonksiyonlari basariyla calistirildi.") print("[BILGI] Test penceresi aciliyor. Cikis icin bir tusa basin...")

try:
cv2.imshow("Kutuphane Dogrulama - Geometrik Test", img) k = cv2.waitKey(0)
cv2.destroyAllWindows()
print("[BASARILI] Grafik arayuz (GUI) sorunsuz

calisiyor.")
except Exception as e:
print(f"[HATA] Grafik arayuz başlatılamadı: {e}") print("Not: Headless (Monitörsüz) modda iseniz bu hata normaldir.")

if name == 'main': opencv_kutuphane_testi()

ÖZGEÇMİŞ

Adı Soyadı | : Ulaş Can Çakmak

Doğum Yeri ve Yılı : Adana, 2002

Medeni Hali | : Bekar
Yabancı Dili | : İngilizce
E-posta | : ulas1173@hotmail.com

Eğitim Durumu

Lise | : Açık Öğretim Lisesi, Mezun

Lisans: Manisa Celal Bayar Üniversitesi Hasan Ferdi Turgutlu Teknoloji Fakültesi Mekatronik Mühendisliği Bölümü, 2021 – Devam Ediyor.

ÖZGEÇMİŞ

Adı Soyadı | : Yavuz Sarı

Doğum Yeri ve Yılı : İzmir, 2004

Medeni Hali | : Bekar
Yabancı Dili | : İngilizce
E-posta | : yavuzsari2004@gmail.com

Eğitim Durumu

Lise | : Adnan Menderes Anadolu Lisesi, Mezun

Lisans: Manisa Celal Bayar Üniversitesi Hasan Ferdi Turgutlu Teknoloji Fakültesi Mekatronik Mühendisliği Bölümü, 2021 – Devam Ediyor.

ÖZGEÇMİŞ

Adı Soyadı | : Halil İbrahim Kurnaz

Doğum Yeri ve Yılı : Malatya, 2001

Medeni Hali | : Bekar
Yabancı Dili | : İngilizce
E-posta | :halil_kurnaz11551143@outlook.com

Eğitim Durumu

Lise | : Mimar Sinan Anadolu Lisesi

Önlisans: Tekirdağ Namık Kemal Üniversitesi Kontrol ve Otomasyon

Lisans: Manisa Celal Bayar Üniversitesi Hasan Ferdi Turgutlu Teknoloji Fakültesi Mekatronik Mühendisliği Bölümü, 2021 – Devam Ediyor.

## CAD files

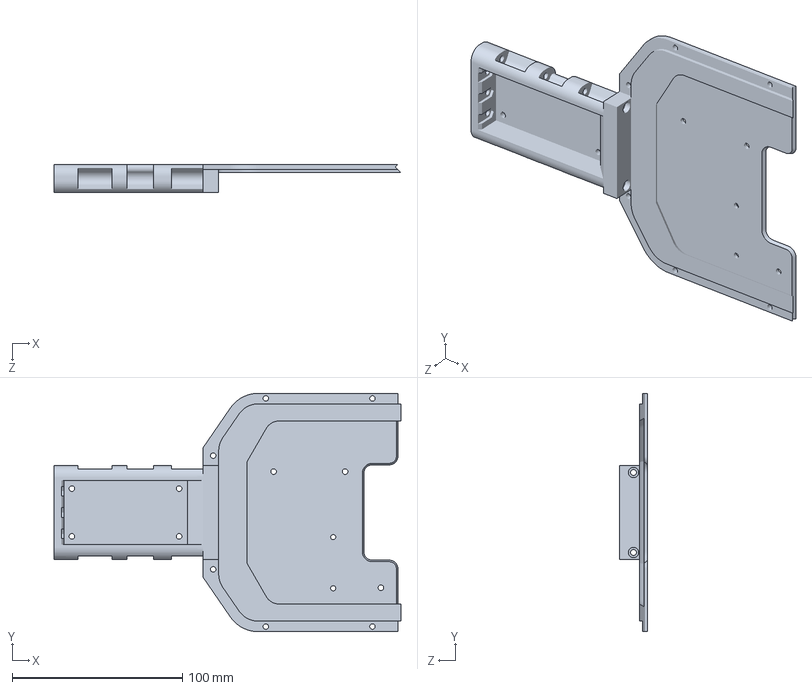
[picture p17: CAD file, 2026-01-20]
Hardware/CAD/Print-2_Cramer_DukeDoks_Rear-Chassis.SLDPRT
203.8 x 140.0 x 16.6 mm

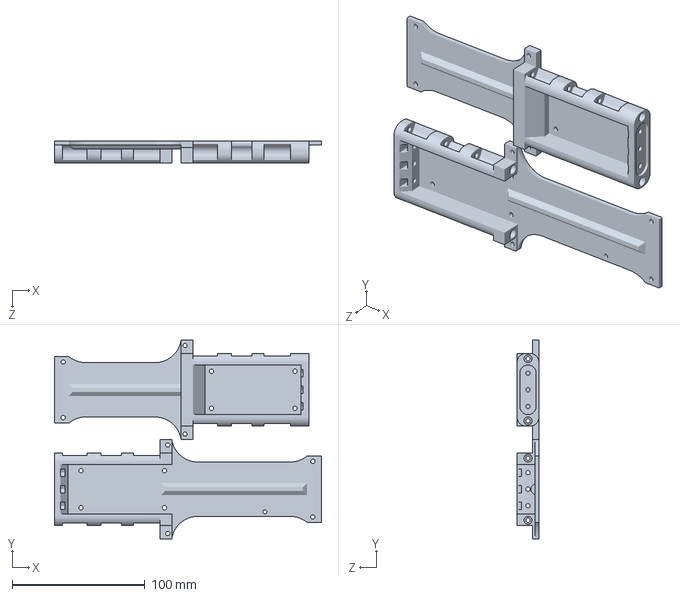
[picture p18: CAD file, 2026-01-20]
Hardware/CAD/Print-3_Cramer_DukeDoks_Bridge.SLDPRT
201.5 x 150.0 x 16.6 mm

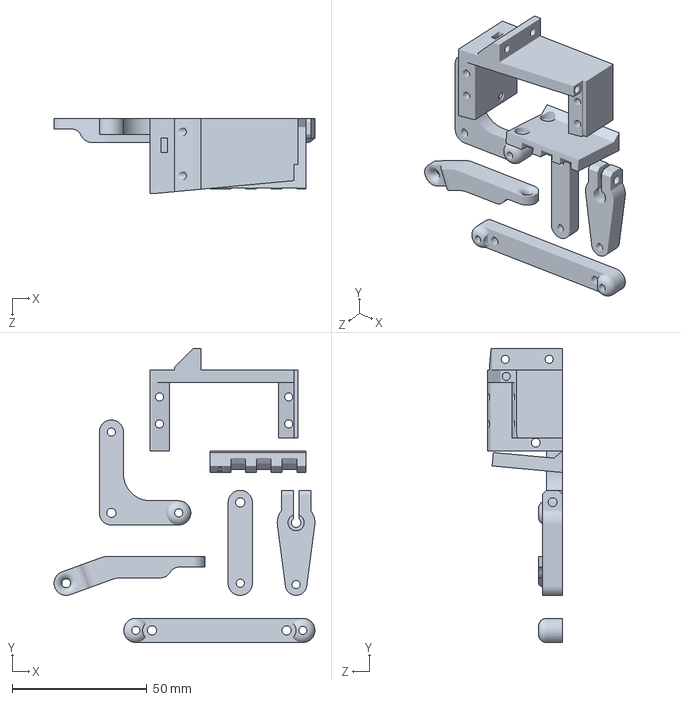
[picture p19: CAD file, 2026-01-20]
Hardware/CAD/Print-13_Cramer_DukeDoks_Steering.SLDPRT
96.9 x 109.2 x 28.0 mm

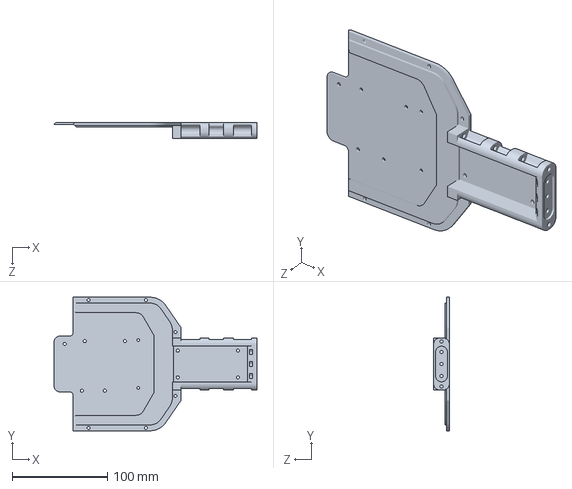
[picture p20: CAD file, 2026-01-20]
Hardware/CAD/Print-1_Cramer_DukeDoks_Front-Chassis.SLDPRT
212.7 x 140.0 x 16.6 mm

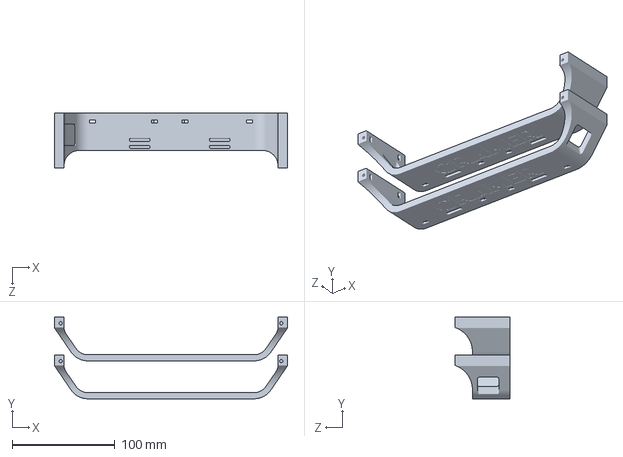
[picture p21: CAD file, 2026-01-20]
Hardware/CAD/Print-4_Cramer_DukeDoks_Body.SLDPRT
226.5 x 79.3 x 53.6 mm

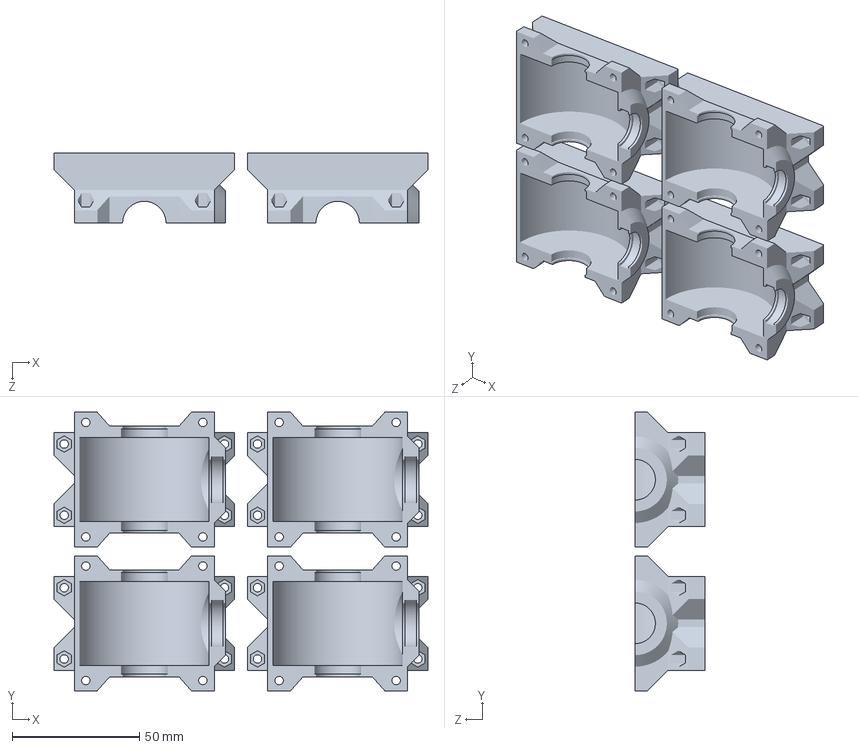
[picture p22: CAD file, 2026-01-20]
Hardware/CAD/Print-8_Cramer_DukeDoks_Differential-Case.SLDPRT
147.0 x 109.5 x 27.5 mm

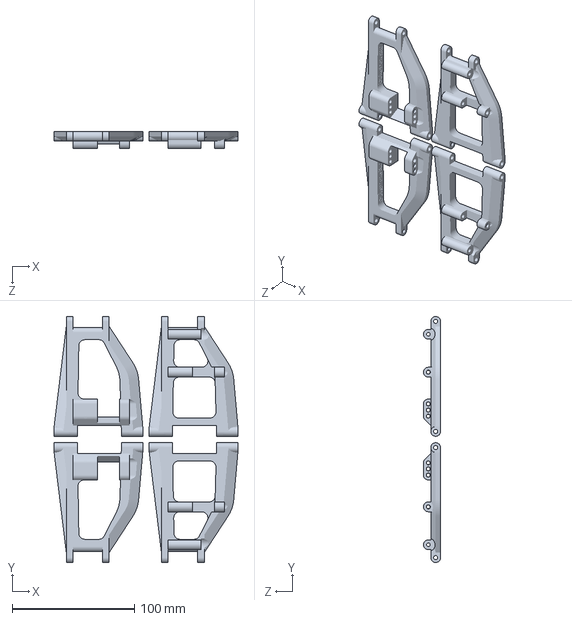
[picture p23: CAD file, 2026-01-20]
Hardware/CAD/Print-5_Cramer_DukeDoks_Swings.SLDPRT
150.3 x 201.2 x 14.0 mm

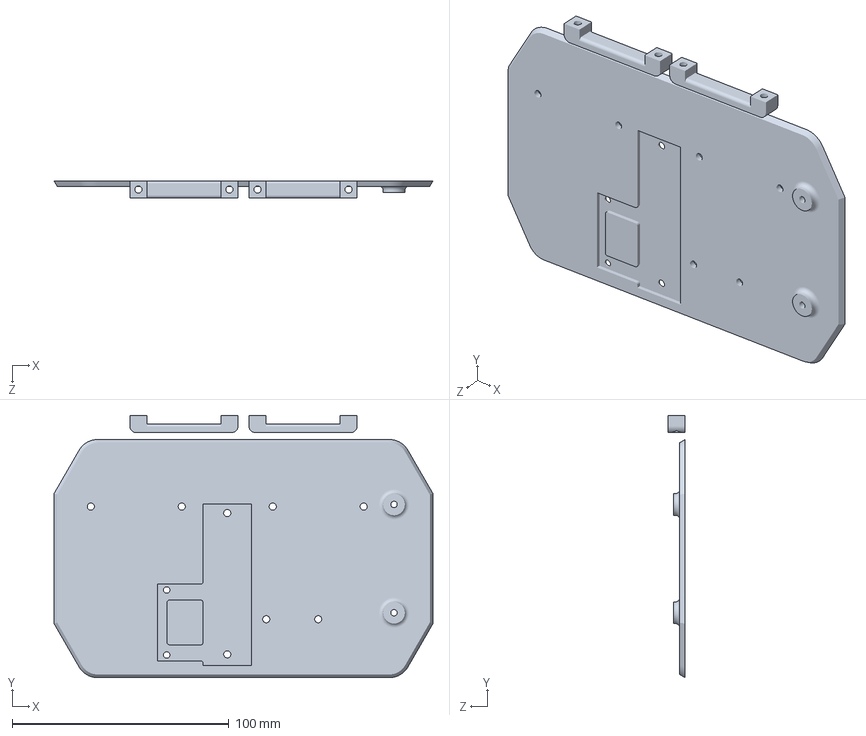
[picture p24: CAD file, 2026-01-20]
Hardware/CAD/Print-7_Cramer_DukeDoks_Internal-Chassis.SLDPRT
175.0 x 121.2 x 8.00 mm

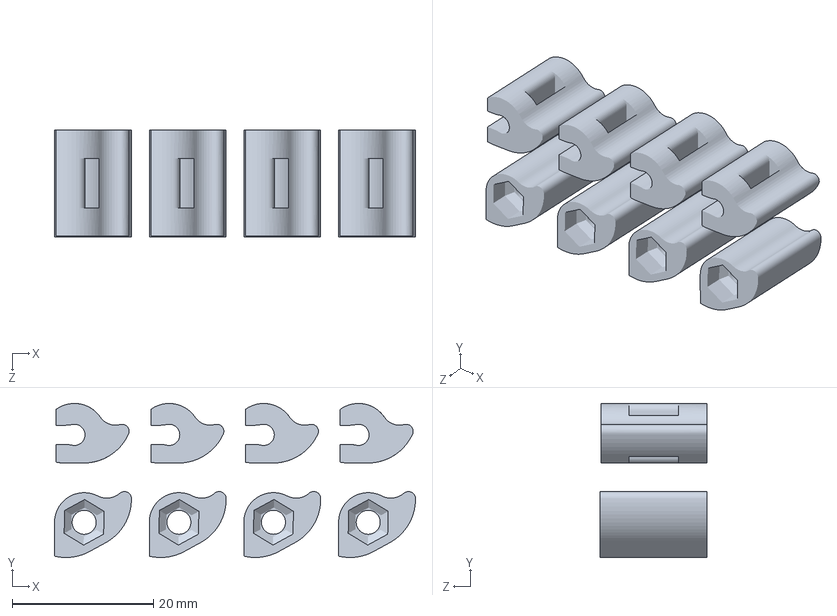
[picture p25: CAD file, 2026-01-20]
Hardware/CAD/Print-14_Cramer_DukeDoks_Nuts-Holders.SLDPRT
51.2 x 21.8 x 15.1 mm

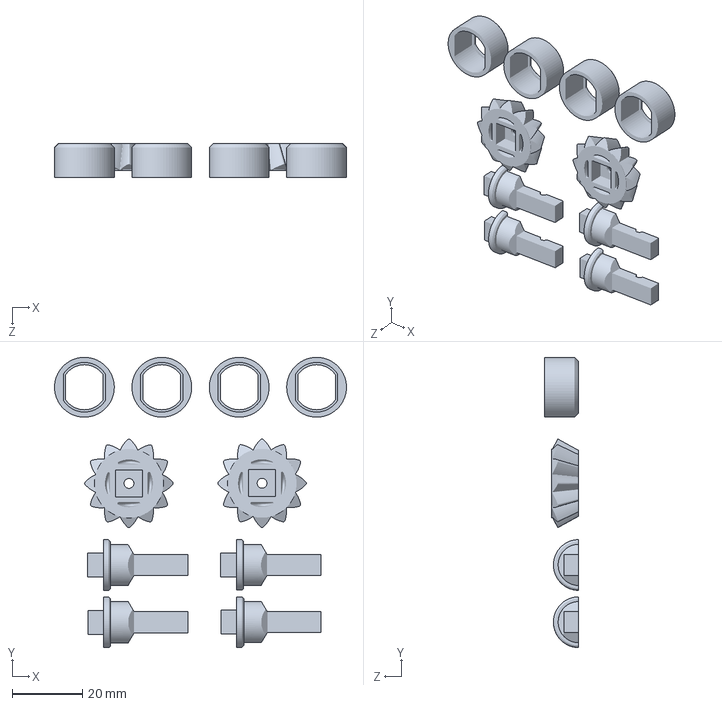
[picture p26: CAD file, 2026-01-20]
Hardware/CAD/Print-10_Cramer_DukeDoks_Transmission_Gear.SLDPRT
83.0 x 82.5 x 9.80 mm

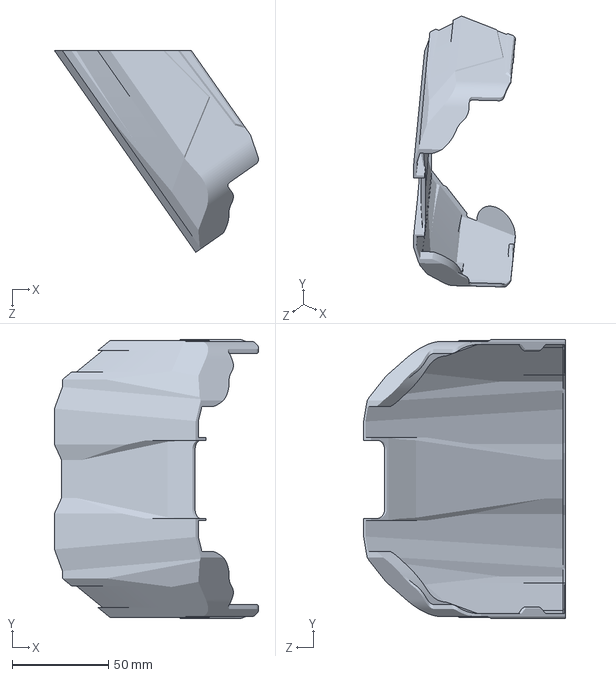
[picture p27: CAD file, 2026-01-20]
Hardware/CAD/Print-15_Cramer_DukeDoks_Basic-Case-Front.SLDPRT
106.2 x 145.2 x 105.0 mm

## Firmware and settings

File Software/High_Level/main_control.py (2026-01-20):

import cv2
from ultralytics import YOLO
import serial
import time

# 1. SERİ HABERLEŞME KURULUMU
try:
    arduino = serial.Serial('/dev/ttyACM0', 9600, timeout=1)
    time.sleep(2)
    print("Arduino Bağlantısı Başarılı.")
except:
    arduino = None
    print("UYARI: Arduino Bulunamadı!")

# 2. YAPAY ZEKA MODELİNİN YÜKLENMESİ
model = YOLO('best.pt')

# 3. KAMERA BAŞLATMA
cap = cv2.VideoCapture(0)
cap.set(3, 640)
cap.set(4, 480)

GUVEN_LIMITI = 0.60

while True:
    success, img = cap.read()
    if not success:
        break

    # 5. MODEL ÇIKARIMI (INFERENCE)
    results = model(img, stream=True, verbose=False)

    for r in results:
        probs = r.probs
        if probs is not None:
            top1_index = probs.top1
            conf = probs.top1conf.item()
            class_name = r.names[top1_index]
            label = f"{class_name} ({conf*100:.1f}%)"

            if conf > GUVEN_LIMITI:
                if "healthy" in class_name.lower():
                    color = (0, 255, 0)
                    if arduino:
                        arduino.write(b'I')
                else:
                    color = (0, 0, 255)
                    if arduino:
                        arduino.write(b'H')

                cv2.putText(img, label, (20, 50), cv2.FONT_HERSHEY_SIMPLEX, 0.8, color, 2)

    cv2.imshow('Otonom Tarim Robotu Kamera', img)
    if cv2.waitKey(1) & 0xFF == ord('q'):
        break

cap.release()
cv2.destroyAllWindows()

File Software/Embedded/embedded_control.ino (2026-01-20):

#include <Servo.h>

Servo ilaclamaServosu;

// Pin Tanımlamaları [cite: 591-597, 686-693]
const int SERVO_PIN = 9;
const int IN1 = 4;
const int IN2 = 5;
const int IN3 = 6;
const int IN4 = 7;
const int ENA = 3;
const int ENB = 11;

char gelen_veri;

void setup() {
  Serial.begin(9600); // UART Haberleşme Başlatma [cite: 600]
  ilaclamaServosu.attach(SERVO_PIN);
  ilaclamaServosu.write(0); // Başlangıç konumu

  pinMode(IN1, OUTPUT);
  pinMode(IN2, OUTPUT);
  pinMode(IN3, OUTPUT);
  pinMode(IN4, OUTPUT);
  pinMode(ENA, OUTPUT);
  pinMode(ENB, OUTPUT);
  
  robotu_durdur(); // Başlangıçta güvenli duruş
}

void loop() {
  if (Serial.available() > 0) {
    gelen_veri = Serial.read(); // Raspberry Pi'den gelen veriyi oku [cite: 614-615]
    
    if (gelen_veri == 'I') { // Durum: SAĞLIKLI -> İlerle [cite: 719]
      ileri_git(150);
      ilaclamaServosu.write(0);
    } 
    else if (gelen_veri == 'H') { // Durum: HASTALIKLI -> Dur ve İlaçla [cite: 620, 733]
      robotu_durdur();
      delay(500);
      ilaclama_yap();
    }
  }
}

void ileri_git(int hiz) {
  digitalWrite(IN1, HIGH);
  digitalWrite(IN2, LOW);
  analogWrite(ENA, hiz);
  digitalWrite(IN3, HIGH);
  digitalWrite(IN4, LOW);
  analogWrite(ENB, hiz);
}

void robotu_durdur() {
  digitalWrite(IN1, LOW);
  digitalWrite(IN2, LOW);
  digitalWrite(IN3, LOW);
  digitalWrite(IN4, LOW);
  analogWrite(ENA, 0);
  analogWrite(ENB, 0);
}

void ilaclama_yap() {
  ilaclamaServosu.write(180); // İlaçlama pozisyonu [cite: 653, 745]
  delay(3000); // 3 saniye ilaçlama [cite: 654, 750]
  ilaclamaServosu.write(0); // Eski konuma dön
  delay(1000);
}
